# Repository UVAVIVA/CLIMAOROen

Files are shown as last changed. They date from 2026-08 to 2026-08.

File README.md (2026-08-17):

# CLIMAOROen

**Open Source Zonal HVAC Control System**

CLIMAOROen is the English version of CLIMAORO, a complete system for centralized heating and cooling control in buildings with underfloor heating and heat pumps, adaptable to all types of systems.

---

## 🌐 Website

[https://UVAVIVA.github.io/CLIMAOROen/](https://UVAVIVA.github.io/CLIMAOROen/)

**🇮🇹 Versione italiana:** [https://UVAVIVA.github.io/CLIMAORO/](https://UVAVIVA.github.io/CLIMAORO/)

---

## 📖 What is CLIMAORO

CLIMAORO is a system that:

- **Optimizes the heat pump** by reducing short cycling
- **Manages multiple zones** centrally with weight-based logic and thresholds
- **Communicates without WiFi** thanks to ESP-NOW (fallback)
- **Works alongside the traditional system** without replacing it
- **Costs less than €15 per thermostat** (compared to €100-250 for commercial systems)

---

## 📷 Thermostats

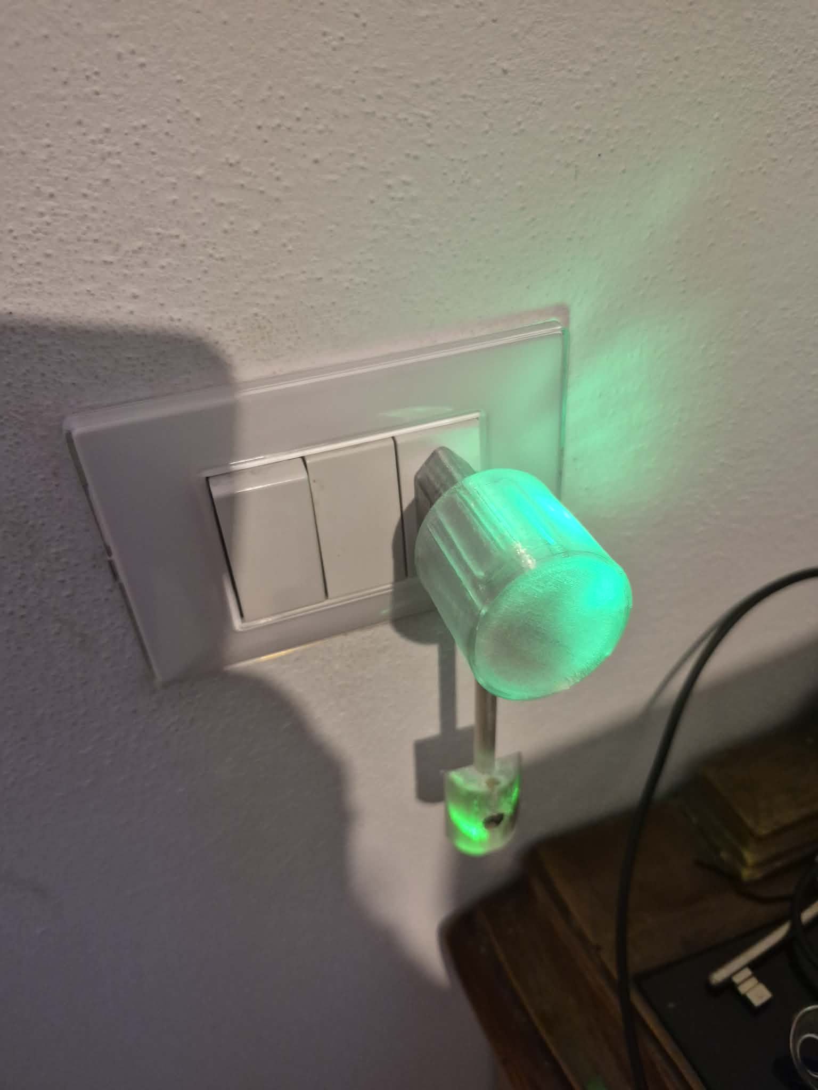
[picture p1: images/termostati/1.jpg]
Thermostat 1
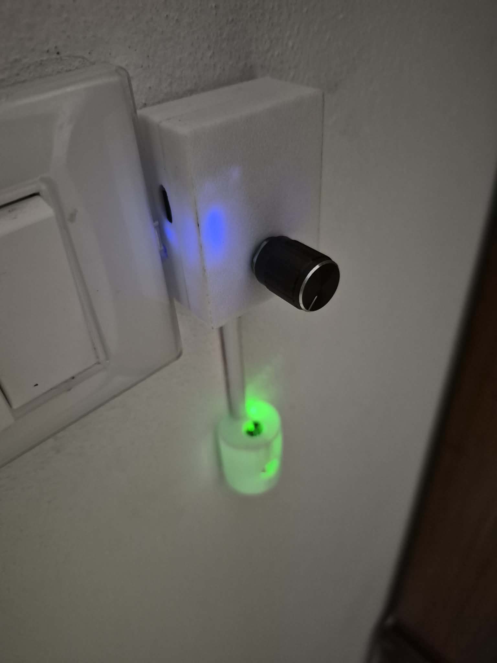
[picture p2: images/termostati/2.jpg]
Thermostat 2
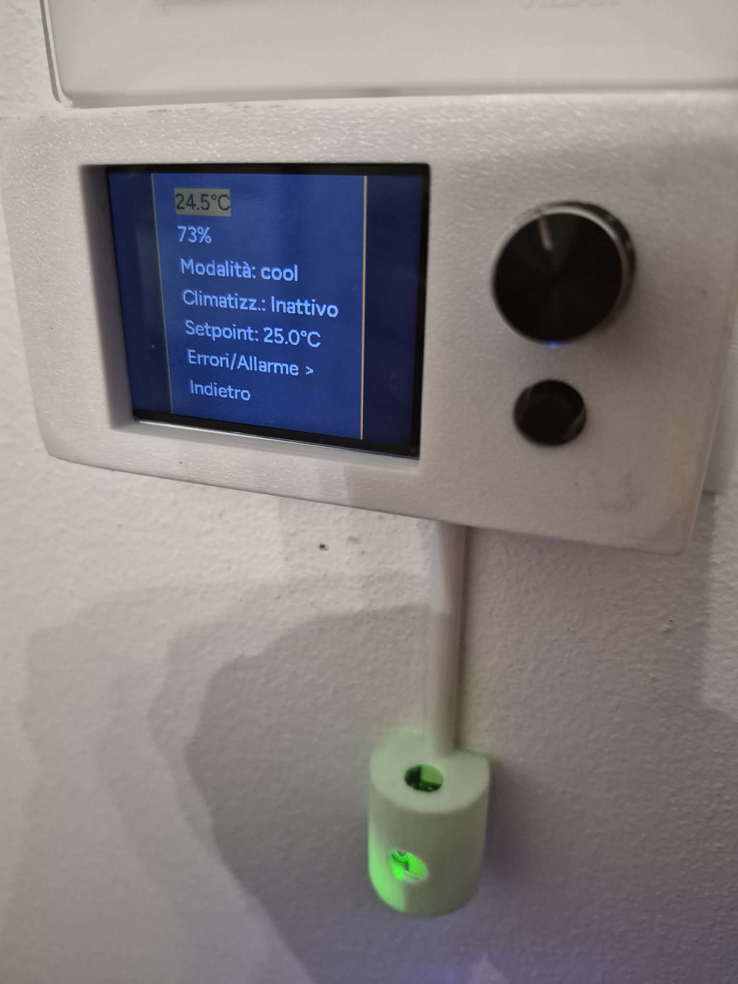
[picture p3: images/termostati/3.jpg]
Thermostat 3
  

---

## 🔧 Project Status

| Feature | Status |
|---|---|
| Summer cooling | ✅ In production |
| Dehumidifiers | ✅ Integrated |
| Photovoltaics | ✅ Integrated |
| Winter logic | 🔄 Ready, waiting for testing |
| Documentation | 📝 Under construction |

---

## 🔌 Mobile thermostat

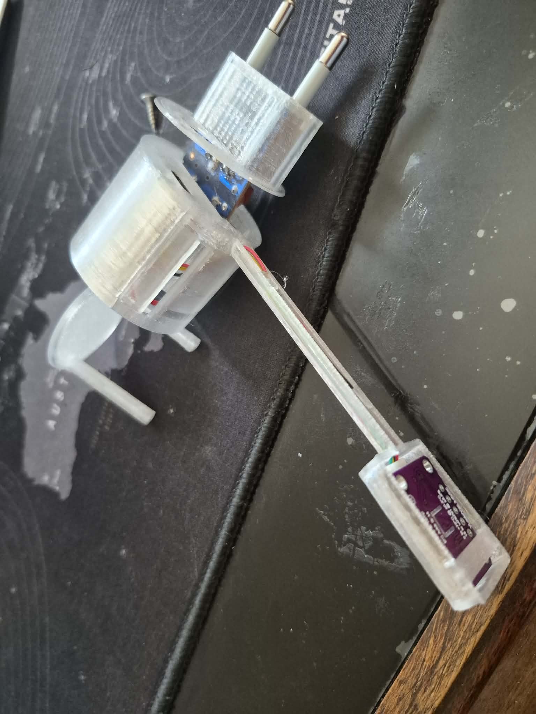
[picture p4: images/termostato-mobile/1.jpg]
Mobile thermostat 1
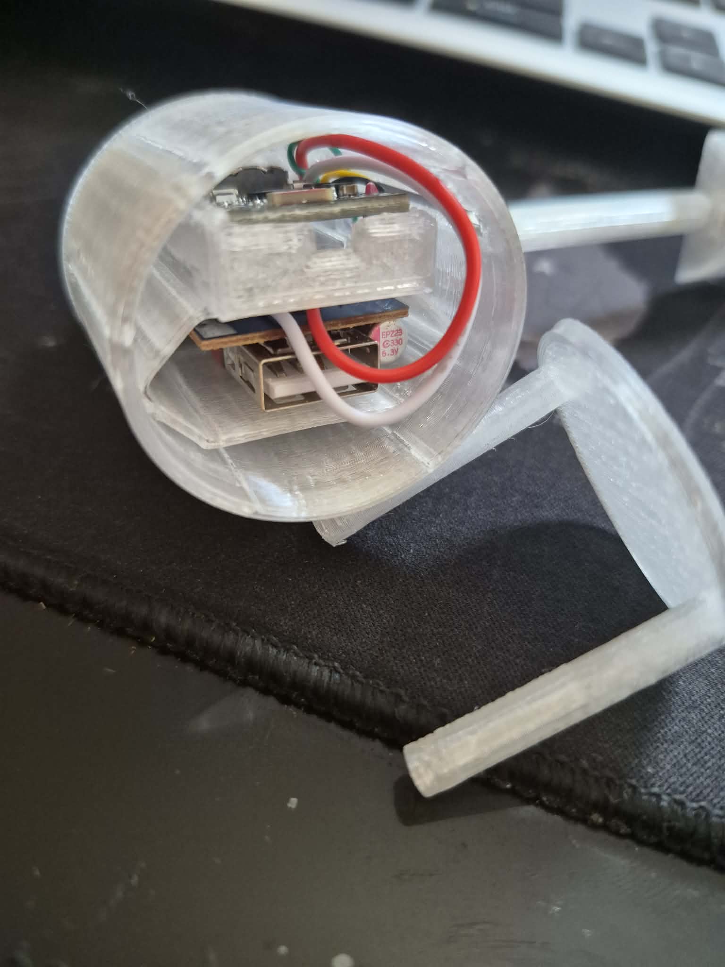
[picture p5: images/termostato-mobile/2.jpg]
Mobile thermostat 2
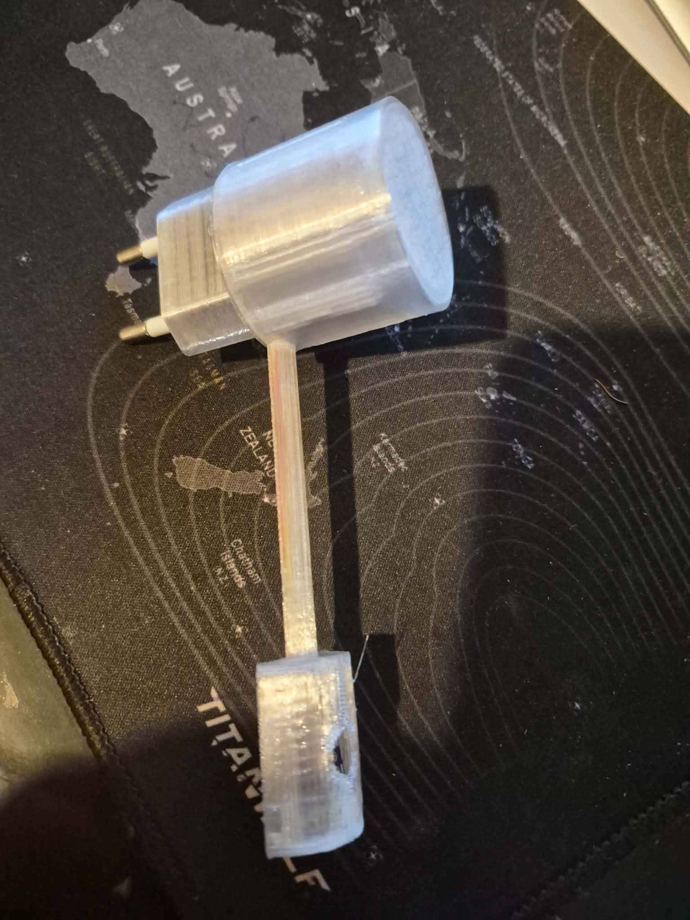
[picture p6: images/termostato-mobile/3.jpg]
Mobile thermostat 3
  

**Part list:**

- [ESP32-C6 board](https://it.aliexpress.com/item/1005007676682081.html)
- [Temperature and humidity sensor (SHT4x)](https://it.aliexpress.com/item/1005009954170157.html)
- [Charger / power supply](https://it.aliexpress.com/item/1005008268805480.html)

**3D printed mobile thermostat case:**

- [termostato-ovale-19-c6.3mf](docs/files/termostato-ovale-19-c6.3mf)
- Recommended material: **PETG**
- Note: the file can only be opened with **OrcaSlicer** or **Flash Studio**

**📋 Assembly tutorial:**

- [Complete thermostat assembly guide](docs/montaggio.md)
- [Website - Assembly page](https://UVAVIVA.github.io/CLIMAOROen/montaggio/)

**Configuration for compilation:**

- [Main config file - ready-to-copy example (English)](https://github.com/UVAVIVA/climaoro-components/blob/main/CLIMAORO_Thermostat-Example.yaml)

---

## 🧩 Main Components

| Component | Description |
|---|---|
| **Thermostats** | ESP32 (S3/C6/C3) devices with sensors, LEDs, and various installation modes (plug-in, 503 box) |
| **Manifold** | Central unit with relays for valves and circulator, with opto-isolated feedback |
| **Centralized logic** | Intelligent control that decides when to turn on the pump based on aggregated demand |

---

## 🎛️ Thermostat with encoder in a 503 box

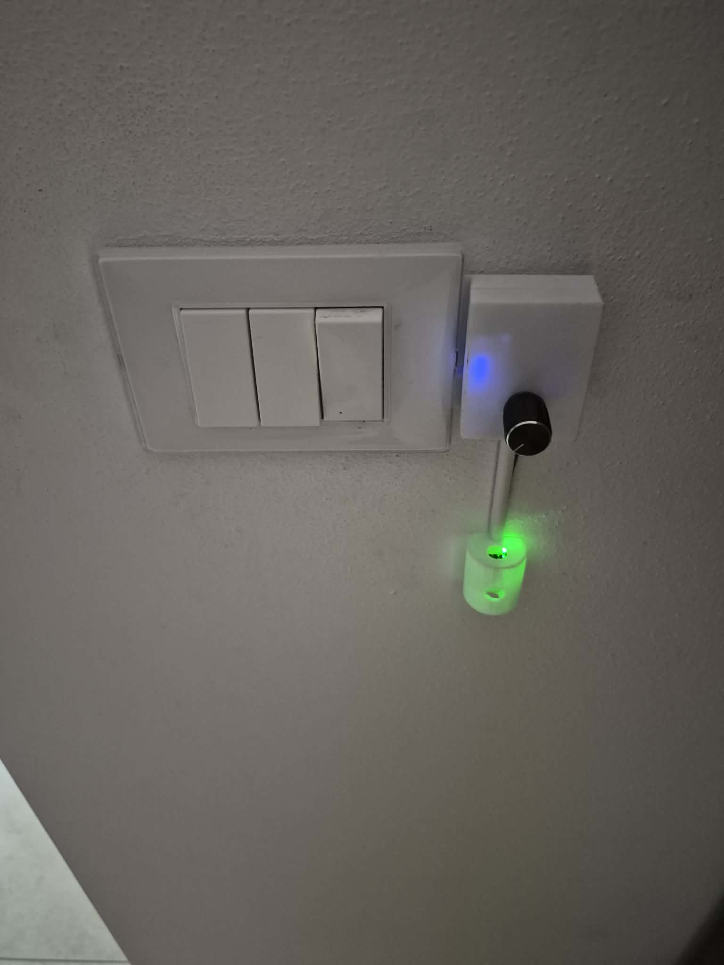
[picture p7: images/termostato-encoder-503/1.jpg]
Thermostat with encoder 503 1
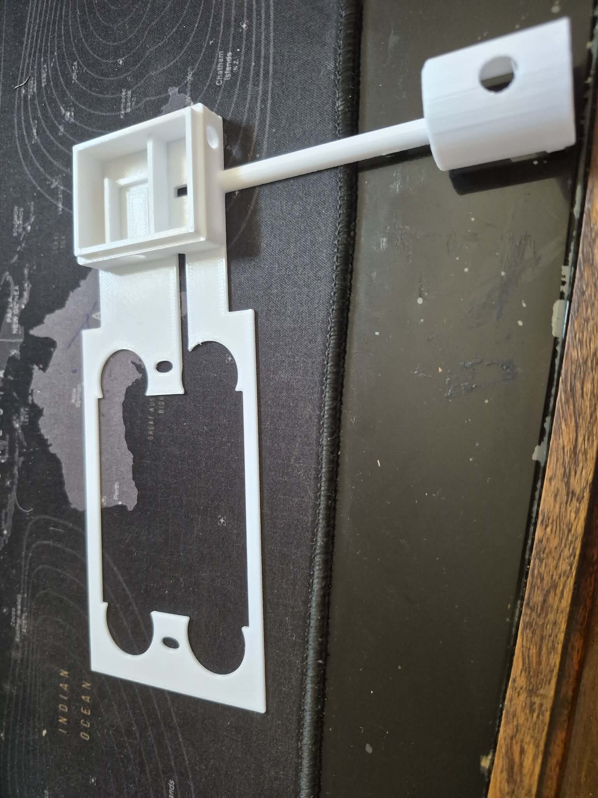
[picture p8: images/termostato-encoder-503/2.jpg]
Thermostat with encoder 503 2
 

**Part list:**

- [ESP32-S3 board](https://it.aliexpress.com/item/1005007171129437.html)
- [Rotary encoder](https://it.aliexpress.com/item/1005012374134834.html)
- [Display](https://it.aliexpress.com/item/1005009260256313.html)

---

## 🤝 LOOKING FOR COLLABORATIONS

This project is open to contributions. I am looking for people with specific skills to help develop and improve the system.

### Areas of interest

| Area | Skills needed |
|---|---|
| **Hardware** | PCB design, component optimization, reliability improvement, cost reduction |
| **Programming** | ESPHome firmware, control logic, Home Assistant integration, interface development |
| **Documentation** | Installation guides, technical manuals, translations |
| **Testing** | Testing on other systems, in different contexts, with different configurations |
| **App development** | Application to generate configurations without touching code |

### Who I'm looking for

People who already know how to work in these areas. The project has reached a level of complexity that requires solid experience: contributors must be able to read and modify code, understand electrical schematics, or document clearly and precisely.

It is not necessary to have experience in all areas, but it is important to have **solid skills in at least one of them**.

### How to contribute

1. Explore the project on [GitHub](https://github.com/UVAVIVA/CLIMAOROen)
2. Open an **issue** to discuss changes
3. **Fork** the repository
4. Submit a **pull request**

📌 **Learn more:** [https://UVAVIVA.github.io/CLIMAOROen/](https://UVAVIVA.github.io/CLIMAOROen/)

---

## 🛠️ Manifold

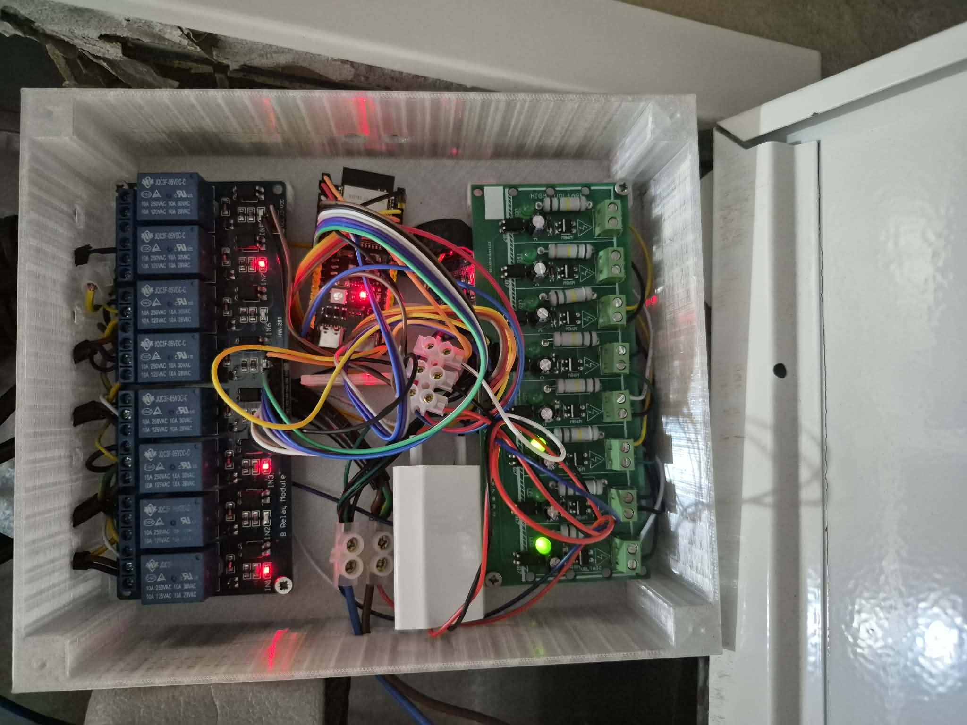
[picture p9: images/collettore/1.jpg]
Manifold 1
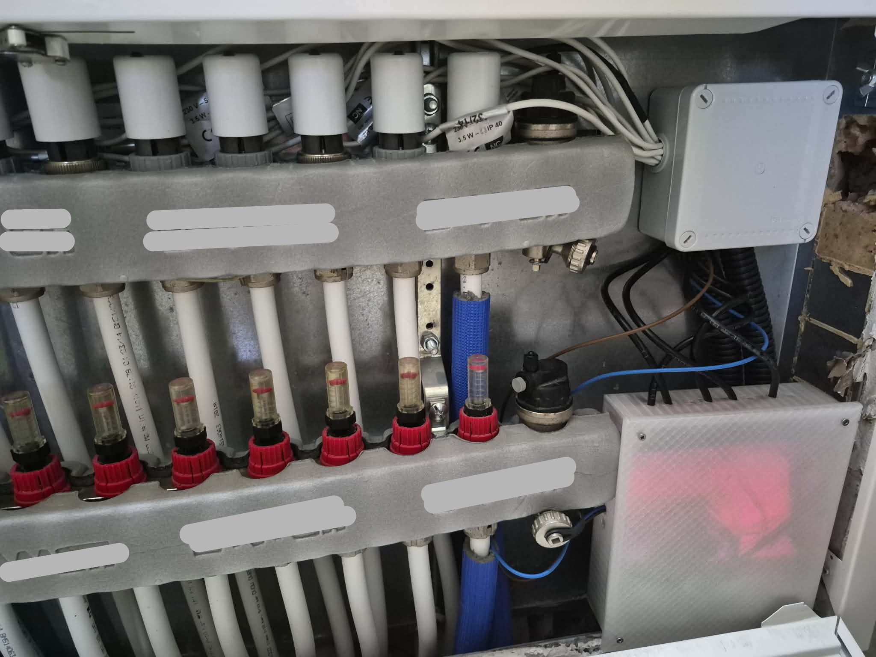
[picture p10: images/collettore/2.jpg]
Manifold 2
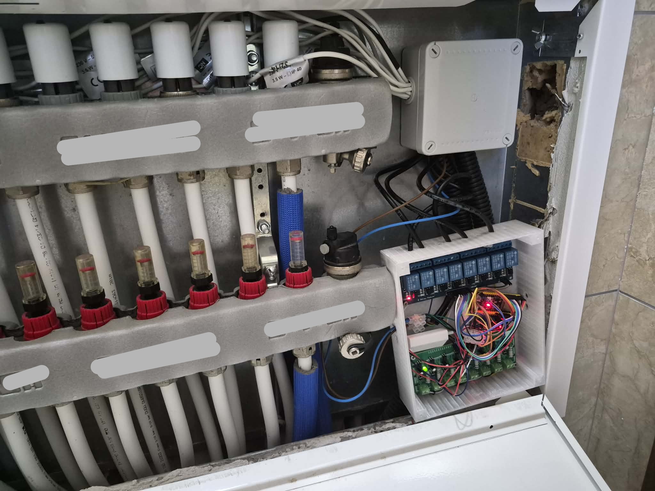
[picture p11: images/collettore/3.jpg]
Manifold 3
  

**Part list:**

- [ESP32-C6 board](https://it.aliexpress.com/item/1005006678253557.html)
- [Relay module (4+ channels)](https://it.aliexpress.com/item/1005007538301230.html)
- [Optocouplers](https://it.aliexpress.com/item/1005009598584430.html)

**Configuration for compilation:**

- [Main config file - ready-to-copy example (English)](https://github.com/UVAVIVA/climaoro-components/blob/main/CLIMAORO_Manifold-Example.yaml)

**📋 Assembly tutorial:**

- [Complete collector assembly guide](docs/collettore_tutorial.md)
- [Website - Collector Assembly page](https://UVAVIVA.github.io/CLIMAOROen/collettore_tutorial/)

---

## 📜 License & Disclaimer

**CLIMAORO © 2026 by UVAVIVA** · License: **MIT with Attribution Condition**

**Terms**
- ✅ Attribution required (in code and on commercial devices)
- ✅ Commercial use permitted (with attribution)
- ✅ Modifications and derivatives allowed
- ✅ Use, copy, distribute and sell permitted

**Disclaimer**
This project is provided **as-is** for educational and experimental purposes.
- ⚠️ Not certified for production use
- ⚠️ ⚡ **DANGER: work on electrical and hydronic (heating) systems must only be performed by qualified personnel**
- ⚠️ No warranties or guarantees provided
- ⚠️ User assumes all risks

**Always follow local electrical codes and safety regulations.**

---

**Built with passion, from scratch.**

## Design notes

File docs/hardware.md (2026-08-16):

# Hardware

## General notes on pins

The pins shown in the diagrams and tables are examples based on current configurations. Each installation may vary depending on the board model used (ESP32-S3, ESP32-C6, ESP32-C3, mini or standard format). Pins should be adapted to your own hardware and needs.

## The manifold

### Compatible microcontrollers

| Chip | Note |
|---|---|
| **ESP32-C6** | Currently used, supports WiFi + ESP-NOW |
| **ESP32-S3** | Valid alternative, more computing power |
| **ESP32-C3** | Compatible, fewer resources but sufficient |

### Components and functions

| Component | Quantity | Function |
|---|---|---|
| Microcontroller | 1 | ESP32-C6/S3/C3 with WiFi + ESP-NOW |
| Relays | 4+ | Zone valve control |
| Relay | 1 | Circulator control |
| Optoisolators | 4+ | Valve feedback |
| LED | 1 | Status signaling |

Manifold 1 Manifold 2 Manifold 3

### Operating logic

| Function | Description |
|---|---|
| Command reception | Receives commands from thermostats via ESP-NOW or WiFi |
| Confirmations | Sends confirmations to thermostats |
| Alarms | Sends alarms in case of anomalies |
| Circulator management | Customizable timing logic |
| Safety timeout | Evaluates shutdown after a preset time |
| Consistency check | Perpetual verification between requested and actual state |
| Feedback | Reading optoisolators to verify valve status |

## The thermostats

### Compatible microcontrollers

| Chip | Note |
|---|---|
| **ESP32-S3** | Recommended for models with display (e.g. Zero mini format) |
| **ESP32-C6** | For models without display or with basic functionality |
| **ESP32-C3** | For compact models or repeaters |

### Models and installations

| Model | Installation | Specific function |
|---|---|---|
| **Mobile** | Electrical outlet | Plug-and-play, standard solution |
| **Internal 503** | Inside 503 box | Local user interface |
| **Side 503** | Side-mounted on 503 box | Compact module, essential controls |
| **Repeater** | Side or inside 503 | ESP-NOW network extension |
| **Panel** | Side or inside 503 | Centralized control, full menu |

Thermostat 1 Thermostat 2 Thermostat 3

### Common features

| Component | Function |
|---|---|
| Microcontroller | Processing and communication (S3, C6 or C3) |
| Sensor | Temperature and humidity sensing |
| LED | Status signaling |
| Communication | WiFi + ESP-NOW (primary and fallback) |

### 3D printed mobile thermostat case

The mobile thermostat case is available for 3D printing.

- **File:** [termostato-ovale-19-c6.3mf](files/termostato-ovale-19-c6.3mf)
- **Recommended material:** PETG
- **Note:** the file can only be opened with **OrcaSlicer** or **Flash Studio**
- **Tutorial:** [Complete assembly guide](montaggio.md)

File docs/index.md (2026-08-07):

# CLIMAOROen

**Open Source Zonal HVAC Control System**

CLIMAOROen is the English version of CLIMAORO, a complete system for centralized heating and cooling control in buildings with underfloor heating and heat pumps, adaptable to all types of systems.

---

**🇮🇹 [Versione italiana](https://UVAVIVA.github.io/CLIMAORO/)**

---

## The story behind this project

I started this project in March 2026. I didn't know how to code. I didn't know how to solder. I didn't know how to 3D print. I only had a problem to solve and the desire to learn.

Today, in August 2026, the system cools for 16 hours a day. The thermostats work. The manifold controls the valves. The logic for winter is ready. The system is already integrated with photovoltaics to optimize summer consumption.

It's not a finished product. It's an evolving project, built piece by piece, day by day. But it already has a professional footprint, and is designed to be replicable, structured, and complete.

---

## Why I built it

### The problem: short cycling

I have an underfloor heating system with an on/off heat pump. In winter, small zones (a bathroom, a small bedroom) require little water. The heat pump always runs at the same power: in two minutes it reaches the flow temperature and turns off. Then it turns on again after ten minutes. Dozens of cycles per day.

Wasted energy. Wear and tear. Inefficiency.

I wanted the pump to turn on only when it's really needed, and to stay on long enough to be efficient.

### Home automation must make sense

Most home automation is a waste of money. Lights that turn on by themselves, automated blinds, voice assistants: they're convenient, but they don't pay for themselves.

Heating and cooling are different. They account for sixty to seventy percent of the bill. Optimizing them delivers real economic returns.

### Commercial thermostats: expensive and closed

A branded WiFi thermostat costs from one hundred euros up to over two hundred and fifty. My thermostat costs less than fifteen euros in components.

But the problem isn't just cost. Commercial systems are often closed: they depend on proprietary clouds, don't integrate freely with Home Assistant, can't be modified or repaired. With DIY you get real customization: you can add features that didn't exist before, adapt the system to your needs, and have full control of your system.

### A solution that leverages ESP-NOW

ESP-NOW is a direct peer-to-peer communication protocol from Espressif. It allows ESP32 devices to communicate with each other without going through a WiFi router. In my system, thermostats talk to the manifold via ESP-NOW as primary or fallback channel. WiFi is used for communication with Home Assistant, but if WiFi goes down, the system continues to work.

Benefits: independence from the router, low latency, encrypted communication. And devices can act as repeaters to extend the network where the signal doesn't reach. A feature that many projects overlook, but which makes the system reliable and robust.

### Building is the real satisfaction

I could have bought commercial thermostats and a control system. But I wouldn't have learned anything. I wouldn't have had full control. I wouldn't have had the satisfaction of building something that didn't exist before.

Building is why this project exists.

---

## 📜 License & Disclaimer

**CLIMAORO © 2026 by UVAVIVA** · License: **MIT with Attribution Condition**

**Terms**
- ✅ Attribution required (in code and on commercial devices)
- ✅ Commercial use permitted (with attribution)
- ✅ Modifications and derivatives allowed
- ✅ Use, copy, distribute and sell permitted

**Disclaimer**
This project is provided **as-is** for educational and experimental purposes.
- ⚠️ Not certified for production use
- ⚠️ ⚡ **DANGER: work on electrical and hydronic (heating) systems must only be performed by qualified personnel**
- ⚠️ No warranties or guarantees provided
- ⚠️ User assumes all risks

**Always follow local electrical codes and safety regulations.**

---

**Built with passion, from scratch.**

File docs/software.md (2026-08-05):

# Software

## Architecture

The control logic is centralized and integrates with Home Assistant. The devices (thermostats and manifold) use ESPHome-based firmware, which allows native integration with Home Assistant and flexible configuration.

## Communication

The system uses two communication channels:

| Channel | Protocol | Purpose |
|---|---|---|
| Primary | WiFi + ESPHome API | Configuration, telemetry, commands from Home Assistant |
| Fallback | ESP-NOW | Direct thermostat ↔ manifold communication (no router) |

## Entities exposed in Home Assistant

| Entity | Type | Description |
|---|---|---|
| climate.*_climatizzazione | climate | Thermostat |
| sensor.*_temperatura_reale | sensor | Ambient temperature |
| sensor.*_umidita_reale | sensor | Ambient humidity |
| sensor.*_stato_sistema | sensor | Operating status |
| sensor.*_ultimo_errore | sensor | Last detected error |
| sensor.*_cronologia_errori | sensor | Error history |
| 
umber.*_temperatura_salvata | 
umber | Reference setpoint |
| 
umber.*_soglia_umidita | 
umber | Humidity threshold for operation lock |
| switch.*_modalita_controllata | switch | Enable centralized control |
| utton.*_rinnovo_modalita | utton | Centralized control timer renewal |
| utton.*_reset_allarme_collettore | utton | Manifold alarm reset |
| utton.*_reset_allarme_circolatore | utton | Circulator alarm reset |
| utton.*_reset_errori | utton | Error reset |
| light.*_led_stato | light | Status LED |

## Centralized control logic

### Configurable parameters per zone

| Parameter | Type | Description |
|---|---|---|
| Weight | Number | Zone importance |
| Inclusion | Boolean | Zone inclusion/exclusion |
| Day standby delta | Number | Standby temperature (day) |
| Night standby delta | Number | Standby temperature (night) |
| Day working delta | Number | Working temperature (day) |
| Night working delta | Number | Working temperature (night) |
| Saved temperature | Number | Reference setpoint |
| Weight threshold | Number | Collective activation threshold |

### Decision flow

1. **Data collection:** real temperature, setpoint, action, mode for each zone
2. **Demand calculation:** for each zone, standby = setpoint - standby_delta; if temp <= standby - 0.5 → requests heat; sum weights
3. **Priority:** zones already running have priority
4. **Collective decision:** if sum_weights >= weight_threshold → activate all
5. **Individual emergency:** if temp <= standby - 0.4 → activate single zone
6. **Execution:** set working setpoint for zones to activate, standby setpoint for zones to deactivate

## LED signaling

Signaling varies depending on configuration and can be customized. As an example:

| State | Typical signal |
|---|---|
| Active operation | Solid color |
| Standby | Different solid color |
| Minor issues | Slow blinking |
| Critical errors | Fast blinking |
| Alarms | Specific blinking |

Signaling functions are configurable and can be adapted to your needs.

## Configuration files

The ESPHome configuration files are public on GitHub in the [climaoro-components](https://github.com/UVAVIVA/climaoro-components) repository.

| File | Link |
|---|---|
| Thermostat - ready-to-copy example (Italian) | [CLIMAORO_Termostato-Esempio.yaml](https://github.com/UVAVIVA/climaoro-components/blob/main/CLIMAORO_Termostato-Esempio.yaml) |
| Thermostat - ready-to-copy example (English) | [CLIMAORO_Thermostat-Example.yaml](https://github.com/UVAVIVA/climaoro-components/blob/main/CLIMAORO_Thermostat-Example.yaml) |
| Thermostat package | [packages/termostato.yaml](https://github.com/UVAVIVA/climaoro-components/blob/main/packages/termostato.yaml) |
| Thermostat with display package | [packages/termostato_display.yaml](https://github.com/UVAVIVA/climaoro-components/blob/main/packages/termostato_display.yaml) |
| Manifold - ready-to-copy example (Italian) | [CLIMAORO_Collettore-Esempio.yaml](https://github.com/UVAVIVA/climaoro-components/blob/main/CLIMAORO_Collettore-Esempio.yaml) |
| Manifold - ready-to-copy example (English) | [CLIMAORO_Manifold-Example.yaml](https://github.com/UVAVIVA/climaoro-components/blob/main/CLIMAORO_Manifold-Example.yaml) |
| Manifold package | [packages/collettore.yaml](https://github.com/UVAVIVA/climaoro-components/blob/main/packages/collettore.yaml) |
| Zone package | [packages/zona.yaml](https://github.com/UVAVIVA/climaoro-components/blob/main/packages/zona.yaml) |

The `secrets.yaml` file (WiFi and API keys) is not published: it must be created locally for each installation.

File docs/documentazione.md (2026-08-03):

# Documentation

## Installation guide

*(Under construction)*

## Electrical schematics

*(Under construction)*

## ESPHome configuration

*(Under construction)*

## System configuration

*(Under construction)*

---

**Detailed documentation is being written. Check back soon for updates.**

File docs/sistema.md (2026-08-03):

# The System

## How it fits in the home

This system does not replace the traditional system. It works alongside it.

The traditional system continues to operate in parallel. In case of smart system failure, simply turn it off and the traditional system takes over. For non-technical people: just turn it off, nothing to understand.

This is a huge advantage over closed commercial systems.

The system was born for an underfloor system with an on/off heat pump, divided into multiple zones, but the idea is applicable to other systems: traditional radiators, mixed systems, air conditioners. Any HVAC system that can be controlled by a thermostat.

## The control logic

The heart of the system is a logic that collectively decides when to turn on the heat pump.

Each zone has a weight (importance: area, heat loss, priority). Each zone has deltas: a standby temperature and a working temperature, separated by day and night. A centralized control system calculates the aggregated demand every minute. If the demand exceeds a threshold, the pump turns on. If a zone is already heating, it has priority.

The result is that the heat pump does not turn on for a single small zone, but only when the overall demand is sufficient. Cycles are longer and less frequent. Lower consumption, less wear, more comfort.

## Why this project is different

This system addresses the problem in its entirety, much more than many solutions currently on the market. It is not a simple WiFi thermostat, not a closed system, not an amateur prototype. It is a complete, replicable, structured system with a professional footprint.

**Clarification:** This project was born out of passion, not for profit. I have no interest in commercializing it directly or profiting from it. However, I am well aware that, due to its completeness and robustness, it could lend itself to professional or commercial use. If someone wanted to use it in this sense — for a condominium system, a public building, a hotel, a new construction — they are free to do so. The project is documented, modular, flexible, and the open source license allows it.

Anyone who wants to install it in a professional context can do so. It can manage multiple zones, integrate photovoltaics, communicate without WiFi, operate alongside a traditional system. It is not a product, but it has the structure to become one. And if someone wants to turn it into a product, they have every right to do so, within the terms of the license.

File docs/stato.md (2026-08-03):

# Status and future developments

## Current status

Summer cooling has been in production for months, sixteen hours a day. Dehumidifiers are integrated and the system is already connected to photovoltaics: solar production is used to manage dehumidification, optimizing consumption when energy is available. Additionally, ambient humidity control prevents reaching the dew point, protecting the system and the house from condensation and mold.

The thermostats work. The manifold controls the valves. The logic for winter is written and ready to be tested.

There are areas for improvement: communication stability in the presence of interference, calibration of weights and thresholds. But the system is there, it works, and it evolves day by day.

## Future developments

There are ideas for the future: an app to generate configuration without touching code, a comparative test between centralized and separate logic. But for now, the priority is thermostats and the manifold. The rest will come later, if and when it makes sense.

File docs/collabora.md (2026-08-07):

# Collaborate

## Looking for collaborations

This project is open to contributions. I am looking for people with specific skills to advance development and improve the system.

**Areas of interest:**

- **Hardware:** PCB design, component optimization, reliability improvement, cost reduction
- **Programming:** ESPHome firmware, control logic, Home Assistant integration, interface development
- **Documentation:** Installation guides, technical manuals, translations
- **Testing:** Testing on other systems, in different contexts, with different configurations
- **App development:** Application to generate configuration without touching code

I am looking for people who already know how to work in these areas. The project has reached a level of complexity that requires solid experience: those who contribute must be able to read and modify code, understand electrical schematics, or document clearly and precisely.

It is not necessary to have experience in all areas, but it is important to have **solid skills in at least one of them**.

## How to contribute

1. Explore the project on [GitHub](https://github.com/UVAVIVA/CLIMAOROen)
2. Open an **issue** to discuss changes
3. **Fork** the repository
4. Submit a **pull request**

📌 **Learn more:** [https://UVAVIVA.github.io/CLIMAOROen/](https://UVAVIVA.github.io/CLIMAOROen/)

---

## 📜 License & Disclaimer

**CLIMAORO © 2026 by UVAVIVA** · License: **MIT with Attribution Condition**

**Terms**
- ✅ Attribution required (in code and on commercial devices)
- ✅ Commercial use permitted (with attribution)
- ✅ Modifications and derivatives allowed
- ✅ Use, copy, distribute and sell permitted

**Disclaimer**
This project is provided **as-is** for educational and experimental purposes.
- ⚠️ Not certified for production use
- ⚠️ ⚡ **DANGER: work on electrical and hydronic (heating) systems must only be performed by qualified personnel**
- ⚠️ No warranties or guarantees provided
- ⚠️ User assumes all risks

**Always follow local electrical codes and safety regulations.**

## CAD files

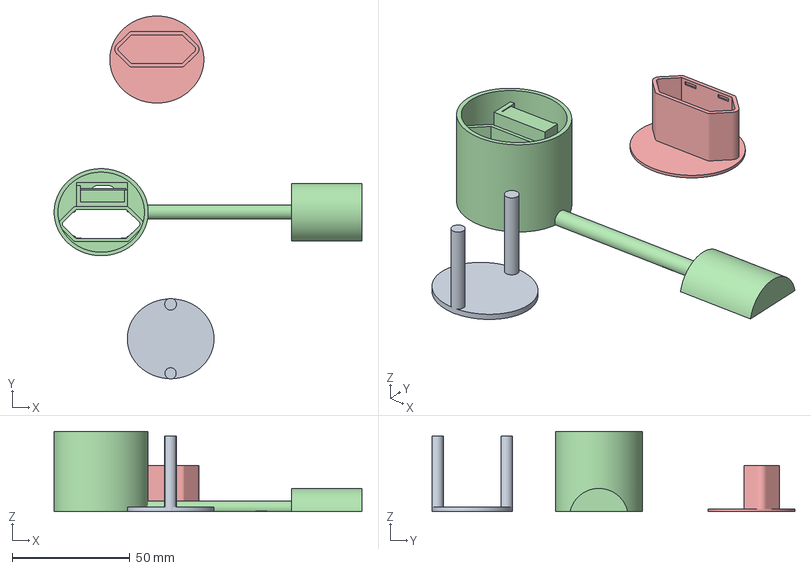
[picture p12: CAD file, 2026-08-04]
docs/files/termostato-ovale-19-c6.3mf
130.8 x 154.3 x 34.0 mm
Assembly x 2

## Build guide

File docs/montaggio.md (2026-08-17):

# Thermostat Assembly

Building the CLIMAORO thermostat: an **ESP32** board powered by a recycled USB
phone charger, connected to an **SHT40** temperature/humidity sensor and placed
inside a **3D printed case** in place of the old wall thermostat.

> ⚠️ **DANGER – MAINS VOLTAGE (230V).** This build is connected to the mains:
> contact with the voltage can cause dangerous electric shocks. **Disconnect the
> power** before any intervention. Never touch the internal components while the
> device is powered. **If you are not experienced with electricity, have a
> qualified electrician do the installation.**

---

## 3D printing the case

The thermostat case is 3D printed. The model is the same one used for the
mobile thermostat:

- **File:** [termostato-ovale-19-c6.3mf](files/termostato-ovale-19-c6.3mf)
- **Recommended material:** PETG
- **Note:** the file can only be opened with **OrcaSlicer** or **Flash Studio**

> ⚠️ **Disclaimer:** the 3D model is provided as-is, for educational and
> experimental purposes. Tolerances may vary depending on printer, material and
> calibration. Not certified for production use.

---

## Assembly steps

### Required materials

| Material | Use |
| --- | --- |
| ESP32 (C3 or C6) | Thermostat brain |
| USB phone charger (5V) | Power supply (recycled) |
| SHT40 sensor (temperature/humidity) | Temperature measurement |
| 3D printed case | Houses PCB, ESP32 and sensor |
| Small screwdriver | Opening the charger |
| Soldering iron + solder | Electrical connections |
| Wire (red, white, green, yellow, black) | Wiring |

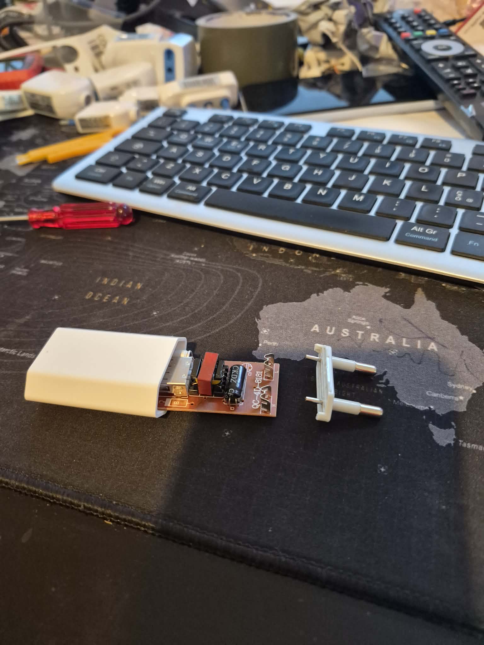
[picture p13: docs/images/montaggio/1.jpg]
Thermostat assembly 1
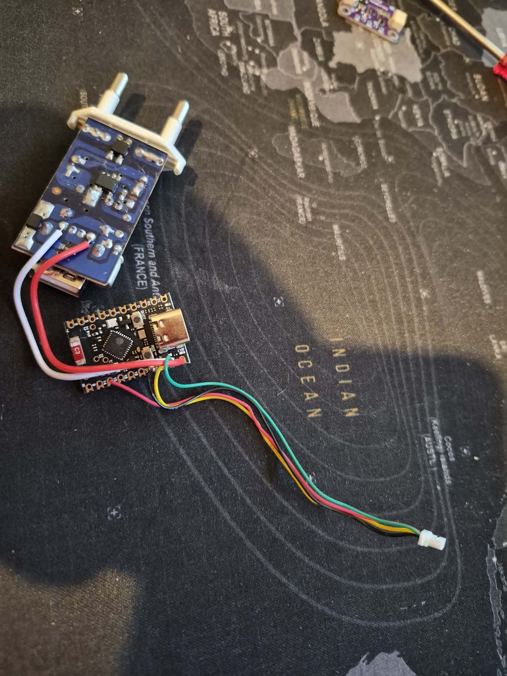
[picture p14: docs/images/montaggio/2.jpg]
Thermostat assembly 2
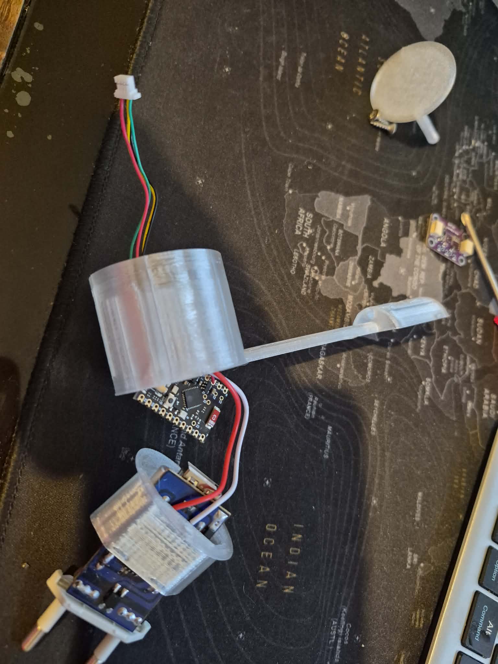
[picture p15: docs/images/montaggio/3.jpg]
Thermostat assembly 3
  

### 1. Open the charger

With a small screwdriver, open the case of the USB phone charger. From the
charger you need two parts:

- the **two metal prongs** (the male contacts that plug into the wall socket,
  where the 230V passes through);
- the **PCB** (the internal board), from which you will take the **5V** to power
  the ESP32.

The charger's plastic case is not used instead: the components will be housed
in the 3D printed case.

### 2. Solder the connections

When soldering is complete, the circuit will look like this:

```
                    ┌─────────────────┐
 USB CHARGER ──────>│    ESP32        │
   (5V from PCB)    │                 │
   VCC (red) ───────> 5V / VIN        │
   GND (white) ─────> GND             │
                    │                 │
 SHT40 SENSOR ─────>│                 │
   VCC (yellow) ────> 3V3             │
   GND (green) ─────> GND             │
   SDA (black) ─────> SDA (i2c pin)   │
   SCL (red) ───────> SCL (i2c pin)   │
                    └─────────────────┘
```

On the charger PCB, solder the **VCC (red)** wire and the **GND (white)** wire.
Also solder the **electrical prongs** that will plug into the base of the wall
thermostat (they carry the 230V supply to the charger).

On the ESP32, solder the two charger wires (power supply) and the four sensor
wires:

- **GND (green)** → GND pin
- **VCC (yellow)** → 3V3 pin
- **SDA (black)** → SDA pin
- **SCL (red)** → SCL pin

> **Note:** the SDA/SCL pins depend on the ESP32 model and are defined in the
> ESPHome configuration file (`i2c_sda` / `i2c_scl`):
> - ESP32-C6 → SDA 20, SCL 14
> - ESP32-C3 → SDA 0, SCL 1

Always check the pins in your YAML file before soldering.

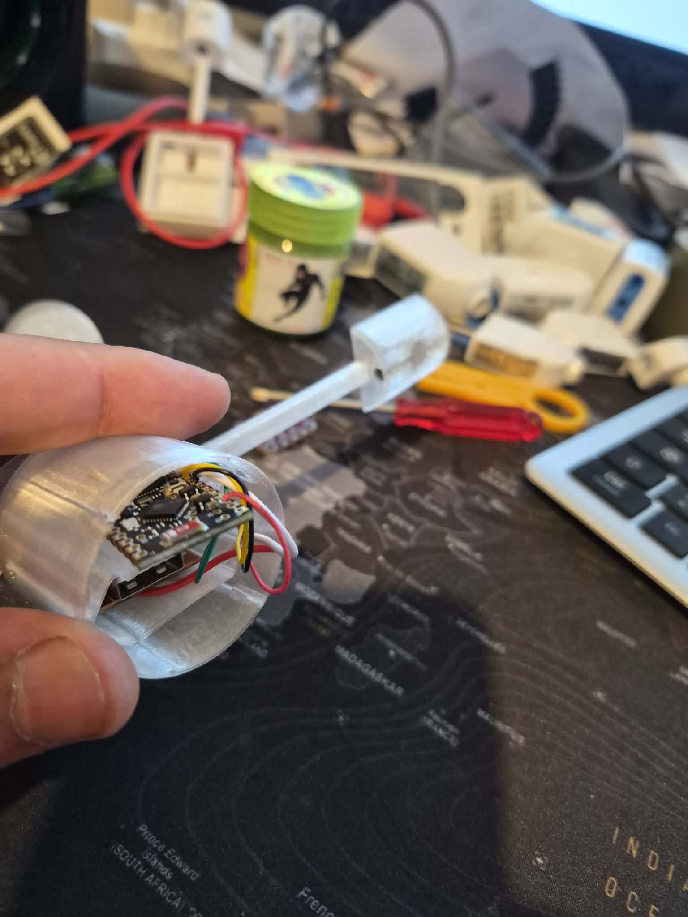
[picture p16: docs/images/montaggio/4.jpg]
Thermostat assembly 4
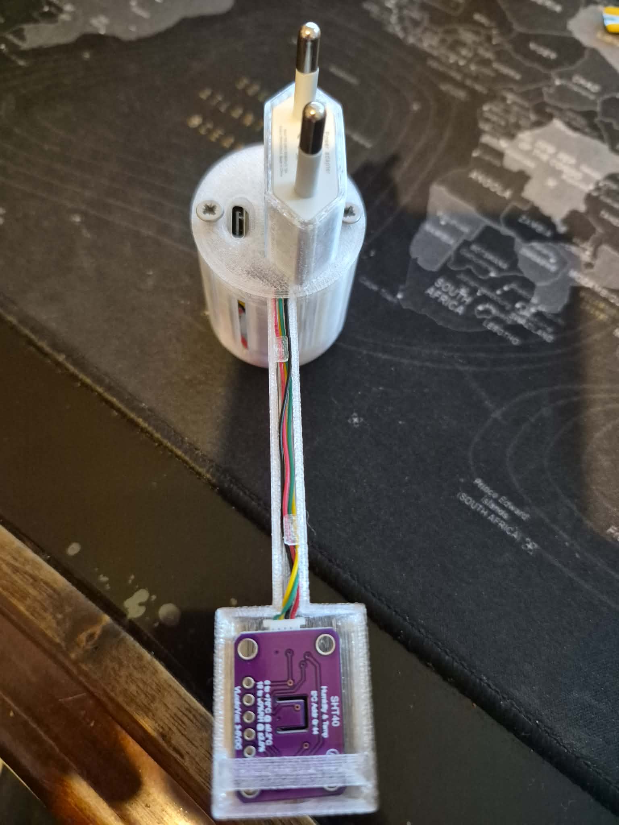
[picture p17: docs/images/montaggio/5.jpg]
Thermostat assembly 5
  Thermostat assembly 6

### 3. Insert the components into the 3D case

Insert the following in this order into the 3D printed case, where the prongs
will act as a lock:

1. the **bundle of wires** (the cables going outside)
2. the **ESP32**
3. the **charger PCB** with the soldered prongs, which will close the thermostat
   plug

### 4. Position the ESP32 and the sensor

Insert the ESP32 into the case housing and route the sensor wires towards the
bottom.

### 5. Close the lid

Insert the thermostat lid with the **slender leg** on the side opposite the
ESP32: that space is the tightest, while the other leg fits with some effort.
Close everything with two screws. Connect the sensor to the four wires and
insert it into its dedicated housing.

---

## Final check

1. Reconnect the power.
2. The thermostat should appear online in Home Assistant (via ESPHome/API).
3. Check that the sensor publishes temperature and humidity.
4. If it does not appear: recheck the solder joints (especially SDA/SCL and the
   power connections) and the charger voltage.

---

## Troubleshooting

### Thermostat keeps rebooting

If the ESP32 reboots when Wi-Fi connects or when communicating with the collector, the problem is almost always the power supply. Old or low-quality USB chargers can't handle the current spikes.

**Solution:** add a **470µF** electrolytic capacitor between 5V and GND, as close to the ESP32 power pins as possible. The capacitor absorbs current spikes and stabilizes the voltage.

Connect it between the **VIN** (or 5V) and **GND** pins of the ESP32, with the positive terminal (+) on 5V and the negative terminal (-) on GND.

---

## Notes

- **⚠️ Safety:** the build contains mains voltage (230V) inside the charger.
  **Always work with the power disconnected**, use insulating materials and
  check the connections before reconnecting the power. Do not expose the device
  to moisture or accidental contact.
- **Responsibility:** this tutorial is for **informational and educational
  purposes**. This is not an industrial product, but an **artisanal** device,
  built and used **without any warranty**. Whoever performs the assembly does so
  at their **own risk and assumes responsibility** for damage to people or
  property resulting from the use of the device.
- **Upcycling:** the USB charger is a recycled component: it just needs to
  provide stable 5V and at least ~1A.
- **Reference:** this tutorial is part of the official
  [CLIMAORO documentation on GitHub](https://github.com/UVAVIVA/CLIMAORO).

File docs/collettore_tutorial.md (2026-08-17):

# The Collector

> ⚠️ **DANGER – MAINS VOLTAGE (230V).** The collector works connected to the mains power supply: contact with voltage can cause dangerous electric shocks. Before any intervention **disconnect the power**. Do not touch internal components while the device is powered. **If you have no experience with electricity, have the installation carried out by a qualified electrician.**

## What is it

The collector is the brain of the centralized system. It is an ESP32-C6 (S3, C3 or other ESP32 models also work) that receives commands from thermostats via ESP-NOW and activates the valves and the circulator. Each collector serves a group of rooms and zones: some rooms have one valve, others have more than one.

Collector 1 Collector 2 Collector 3

## Required components

- [ESP32-C6 board](https://it.aliexpress.com/item/1005006678253557.html) (or S3/C3): collector brain
- [Relay module (4+ channels)](https://it.aliexpress.com/item/1005007538301230.html): one relay per valve + one relay for the circulator
- [Optocouplers](https://it.aliexpress.com/item/1005009598584430.html): one optocoupler per valve, provides status feedback
- Charger/Power supply: one or more, converts 220V to 5V for ESP32 and relays

## Power supply

The system operates at two voltage levels:

- 220V → enters the charger, which converts to 5V to power the ESP32 and relay boards
- 3.3V → powers the optocouplers and relay signals

AC side (220V): optocouplers connect to neutral.

## Relay → valve connections

Each relay has three terminals:

- COM (common): connected to the valve and the optocoupler
- NC (normally closed): connected to the old thermostat, which can continue to work as backup
- NO (normally open): connected to 220V (or the valve's voltage, if different)

When the relay activates, the circuit switches from NC to NO: the old thermostat disconnects and the valve receives power from the new supply. When the relay returns to rest, the circuit switches back to NC and the old thermostat resumes control.

## Optocoupler → feedback connection

The optocoupler connects to the relay's COM. When the relay activates and the valve receives power, the optocoupler detects it and sends a confirmation signal to the ESP32. This way the collector knows the valve has actually opened.

If the relay is active but the optocoupler does not confirm, the collector reports an error (the relay may be faulty or the valve stuck).

## Circulator relay

The circulator has a dedicated relay. Unlike the valves, only COM and NO are used here: when the relay activates, the circuit closes and the circulator starts. The collector manages a startup delay (waits until at least one valve is open) and a delayed shutdown (after the last valve closes).

## Safety logic

- Zone timeout: each valve has a maximum open time limit (2 hours). If a thermostat stops communicating (e.g. disconnects), the collector turns off the valve after the timeout to prevent it from staying on uncontrolled. If the thermostat comes back online and requests to turn on again, the collector does it immediately.
- Coherence check: every 2 minutes the collector verifies that the relay state matches the optocoupler feedback. If there is a discrepancy, it reports an error.
- Circulator alarm: if the circulator doesn't start despite the request, the collector sends an alarm to all thermostats.

## Common troubleshooting

### ESP32 brownouts and reboots

If the ESP32 reboots when relays activate (especially with multiple valves simultaneously), the problem is almost always the power supply. The current spike drawn by the relay coils drops the voltage below 3V and the ESP32 reboots on its own (brownout).

**Solution:** buffer capacitors on the 5V power supply:

| Type | Value | Use |
|---|---|-----|
| Electrolytic | **470µF** | General buffer, absorbs relay current spikes |
| Electrolytic | **1000µF** | For systems with 4+ relays, greater buffer capacity |
| Ceramic | **100nF (0.1µF)** | Filters high-frequency noise, placed near ESP32 power pins |

**Connection:** capacitors go between 5V and GND, as close to the ESP32 as possible. The ceramic goes directly on the board's VIN/GND pins, the larger electrolytic on the power rail.

**Important note:** the ceramic capacitor (100nF) does NOT replace the electrolytic and vice versa. The electrolytic handles large spikes (relays), the ceramic filters fine noise. Use them together.

### Optocouplers not confirming

If the relay is active but feedback doesn't arrive:

1. Check that the optocoupler is connected to the correct relay's COM
2. Verify the feedback GPIO isn't already used for something else
3. Measure with a multimeter if the opto pin changes state when the relay activates

### Valves not opening

1. Verify the relay is actually active (LED on the relay board)
2. Check the wire from the valve to the relay is properly connected
3. Measure voltage at the valve terminals: should be ~220V when relay is active
4. Check the valve isn't mechanically stuck (try manually actuating it)

### Circulator not starting

1. Verify the circulator relay is active
2. Check the startup delay (circulator starts only after at least one valve is open)
3. Ensure the output voltage is correct

## Materials and wiring

- 1.5mm² wire for 220V power supply (L and N)
- AWG24 or AWG20 wire for relay COM, NO and NC
- Terminal blocks for fixed junctions
- Crimp connectors for quick connections
- Snap connectors for solderless connections

## 220V Section

### Mains power

Domestic 220V mains enters the charger through the L (live) and N (neutral) lines. The charger converts 220V to 5V to power the ESP32 and relay boards.

### Valve relays

Each valve is controlled by a three-terminal relay:

- **NO** → connected to live (L) at 220V
- **COM** → connected to the valve and the optocoupler
- **NC** → connected to the old thermostat (manual fallback)

When the relay activates, the circuit switches from NC to NO: the valve receives power and opens. When it returns to rest, the old thermostat resumes control.

> **Note:** This guide describes a 220V AC system. For systems with different voltage or DC current, the connections must be modified according to the specifications of the valves and power supply used.

### Circulator relay

The circulator has a dedicated relay with only COM and NO:

- **COM** → input from the circulator
- **NO** → circulator consensus output

When the relay activates, the circulator starts. The collector manages a startup delay and delayed shutdown.

### Optocouplers

Each optocoupler monitors the state of the corresponding relay:

- **N** → neutral (shared with the charger)
- **COM** → connected to the relay's COM

When the relay activates, the opto detects it and sends feedback to the ESP32.

### 220V electrical schematic

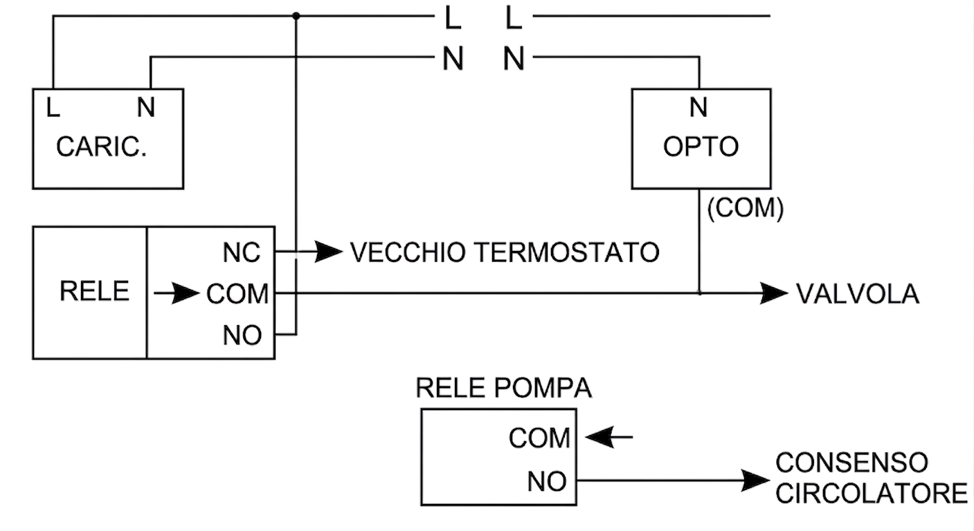
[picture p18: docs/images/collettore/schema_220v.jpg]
220V electrical schematic


## Low Voltage Section

### 5V power supply

The charger provides 5V that powers:

- **ESP32-C6** → through the VIN or 5V pin on the board
- **Relay board** → relays receive 5V for the coils

The charger's GND must be connected to the ESP32 and relay board GND.

### 3.3V power supply

The ESP32 provides 3.3V from the dedicated pin. This voltage powers:

- **Optocouplers** → each opto receives 3.3V for the digital side
- **Relay signals** → relay pins operate at 3.3V

GND is common to the entire system.

### ESP32 → Relay connections

Each relay is controlled by an OUTPUT GPIO pin on the ESP32. When the GPIO goes high (3.3V), the relay activates.

| Zone | Relay Pin |
|---|---|
| 1 | GPIO0 |
| 2 | GPIO1 |
| 3 | GPIO10 |
| 4 | GPIO11 |
| Circulator | GPIO3 |
| LED | GPIO8 |

### Optocouplers → ESP32 connections

Each optocoupler provides feedback on the corresponding relay state through an INPUT GPIO pin. When the relay activates and the opto detects current, it sends a signal to the ESP32 GPIO.

| Zone | Feedback Pin |
|---|---|
| 1 | GPIO20 |
| 2 | GPIO21 |
| 3 | GPIO22 |
| 4 | GPIO23 |

### Optocoupler → relay connections (AC side)

The AC side of the optocoupler connects to the corresponding relay's COM. This allows the opto to detect when the relay is active and the valve is receiving power.

### Low voltage schematic

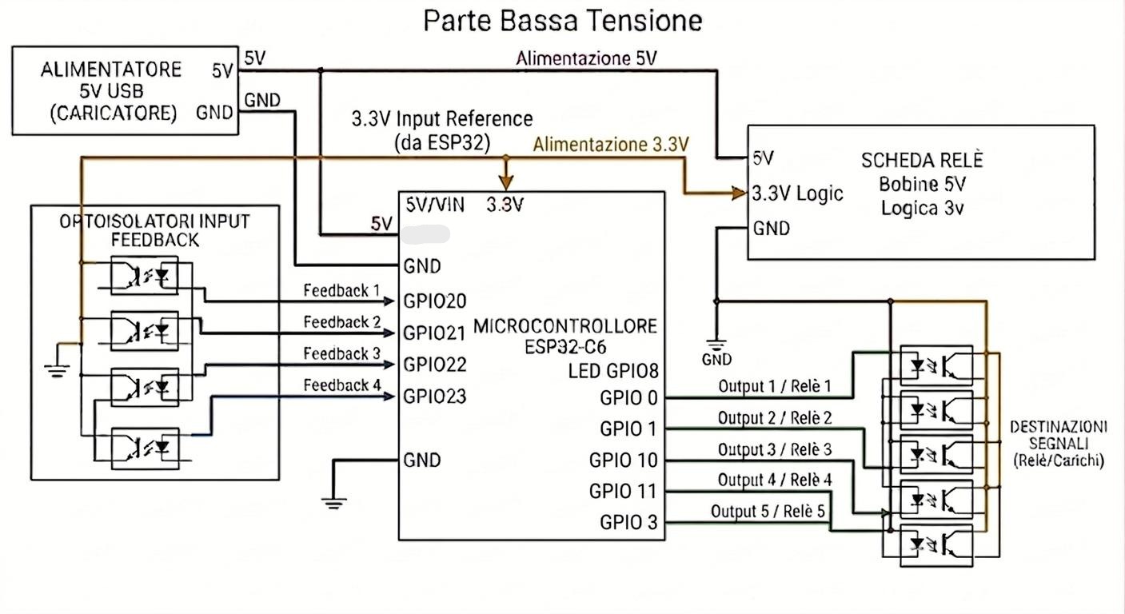
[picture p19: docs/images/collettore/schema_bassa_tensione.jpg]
Low voltage schematic


---

## Notes

- **⚠️ Safety:** the collector contains mains voltage (230V). **Always work with power disconnected**, use insulated materials and verify connections before reconnecting power. Do not expose the device to humidity or accidental contact.
- **Disclaimer:** this tutorial is for **informational and educational purposes only**. It is not an industrial product, but a **handmade** device, built and used **without any warranty**. Anyone performing the assembly does so **at their own risk and assumes responsibility** for any damage to people or property resulting from the use of the device.
- **Reference:** this tutorial is part of the official documentation [CLIMAORO on GitHub](https://github.com/UVAVIVA/CLIMAOROen).

**📋 Thermostat assembly tutorial:**

- [Complete guide to thermostat assembly](montaggio.md)
- [Website - Assembly page](https://UVAVIVA.github.io/CLIMAOROen/montaggio/)

**Build configuration:**

- [Main collector config - ready to copy example (English)](https://github.com/UVAVIVA/climaoro-components/blob/main/CLIMAORO_Collector-Example.yaml)

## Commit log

2026-08-03 Aggiunto file verifica Google Search Console per il sito inglese
2026-08-04 Scambiati gruppi foto mobile/encoder e aggiunta part list AliExpress
2026-08-04 Aggiunte foto collettore e termostati in hardware.md, case stampa 3D termostato mobile (PETG) e link versione italiana in home
    [termostato-ovale-19-c6.3mf]
2026-08-06 Aggiunge .gitignore (esclude output di build site/)
2026-08-06 Passa alla licenza MIT con Condizione di Attribuzione (codice + dispositivi commerciali)
2026-08-16 Adds thermostat assembly tutorial (page + 6 photos); nav entry, link from hardware and README (English)
2026-08-17 Add collector tutorial with schematics and cross-links
